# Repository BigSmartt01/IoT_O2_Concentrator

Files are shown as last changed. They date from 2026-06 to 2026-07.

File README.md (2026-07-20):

# IoT Oxygen Concentrator Integration

**Purity Monitoring, Alert System and Compressor Control**

A non-invasive integration module for PSA oxygen concentrators. The system monitors
oxygen purity on the outlet line, escalates alerts through five tiers as purity drops,
notifies a caregiver via SMS or voice call, and cuts compressor power only at true
system failure levels.

---
<p align="center">
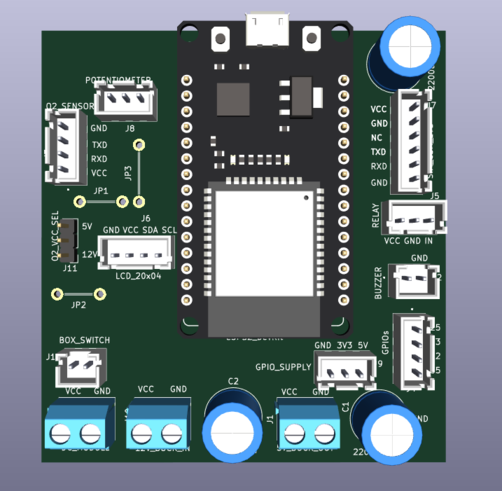
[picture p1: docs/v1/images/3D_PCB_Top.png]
  
</p>

## What This System Does

| Feature | Description |
|---|---|
| Purity monitoring | OCS-3FL2.0 ultrasonic sensor on post-filtration outlet (UART2) |
| Local display | LCD 2004 (I2C) shows O2%, flow, temperature, status, GSM signal, uptime |
| Five-tier alerts | NORMAL → WARNING → DANGER → SEVERE → CRITICAL, each with distinct buzzer pattern and response |
| Caregiver config | Number stored in NVS flash — configurable via USB serial, SMS command, **or the web portal** |
| Three input modes | Potentiometer (demo), WiFi captive portal (demo sliders), or real Sensor (UART) |
| Boot illusion | On boot, simulates a sensor warm-up ramp until a real sensor is connected — no hardware required to demo |
| Fail-safe relay | Compressor only cuts at CRITICAL (near-ambient O2, sustained) — every other tier keeps it running while alerting |

The concentrator itself is **not modified**. All integration is external in a separate enclosure.

---

## Hardware

| Component | Role |
|---|---|
| ESP32 DevKit (standard) | Main microcontroller, 3 UARTs, WiFi AP for captive portal |
| OCS-3FL2.0 sensor | Oxygen purity, flow, temperature (UART2, 12-byte packet) |
| SIM800L GSM EVB | SMS and voice call via Nigerian GSM network (UART1) |
| LCD 2004 + I2C backpack | Local display, 4 rows |
| 5V relay module + NPN driver (BC337) | Compressor power control, active-HIGH from GPIO |
| Active buzzer (5V) | Audible alert, pattern varies by tier |
| LM2596 buck converter | 12V to 5V regulated rail |
| 12V AC-DC module | Mains AC to 12V DC from concentrator supply |
| 2200uF electrolytic caps (x3) | Bulk capacitance on 5V rail, 12V rail, and SIM800L supply |
| Potentiometer 10k | Demo sensor substitute (ADC, GPIO 34) |

Full wiring, schematic, and PCB layout are documented in `docs/`.

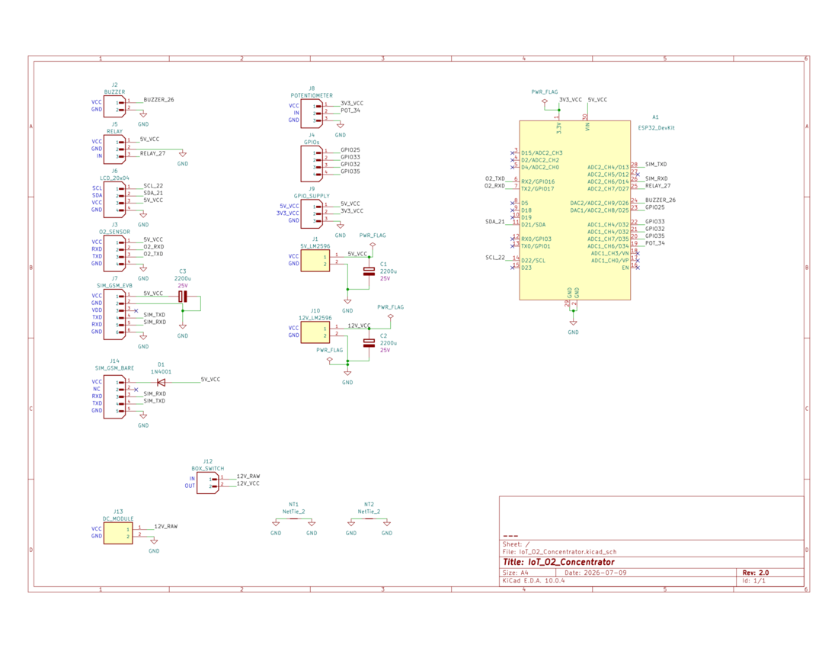
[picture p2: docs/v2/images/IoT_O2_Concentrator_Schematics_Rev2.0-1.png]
Schematic


---

## Project Structure

```
project-root/
├── firmware/               # Arduino sketch (.ino), config.h, portal_html.h
├── hardware/                # KiCad schematic, PCB layout, Gerber files
├── docs/                    # Full project documentation, diagrams, images
├── README.md                # This file
├── SETUP.md                 # Step-by-step setup guide for Arduino IDE
└── .gitignore
```

---

## Alert Tiers

The system escalates through five tiers based on O2 purity. Only the DANGER tier
and above place a voice call; only WARNING sends SMS. **The compressor keeps running
through every tier except CRITICAL** — the design assumes a caregiver may not respond
immediately, so oxygen delivery is only stopped once purity has effectively fallen to
ambient air levels, at which point the compressor was providing no therapeutic value anyway.

| Tier | O2 Purity | Buzzer | Caregiver Contact | Relay |
|---|---|---|---|---|
| NORMAL | ≥ 85% | Silent | — | ON |
| WARNING | 70% – 85% | Single beep, 1s cycle | SMS | ON |
| DANGER | 35% – 70% | Double beep, 1s cycle | Voice call | ON |
| SEVERE | 23% – 35% | Continuous tone | Voice call | ON |
| CRITICAL | < 23% (3 consecutive readings) | Continuous tone | Voice call | **OFF** |

Thresholds are runtime-adjustable (see [Configuration](#configuration-thresholds-and-caregiver-number) below)
and persist in NVS flash. Default fallback values live in `firmware/config.h`.

All alerts are suppressed for **30 seconds after boot** to allow the sensor warm-up
and GSM network registration to settle before any buzzer, SMS, or call can fire.

---

## Input Modes

The system supports three interchangeable data sources, switchable at any time from
the web portal without reflashing:

- **Potentiometer** — a physical demo knob on GPIO 34, mapped to 21%–95.6%
- **WiFi** — connect to the device's own captive portal and drag sliders for O2, flow, and temperature
- **Sensor** *(boots here by default)* — real UART2 data from the OCS-3FL2.0. If no real sensor is connected, the system runs a realistic warm-up illusion (ramping 21% → ~92% over ~15 seconds, then settling with slight jitter) so the full alert chain can be demonstrated with no hardware attached. The moment a real sensor sends valid packets, live data takes over automatically.

<p align="center">
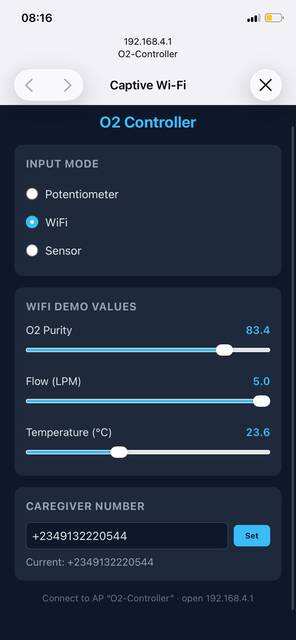
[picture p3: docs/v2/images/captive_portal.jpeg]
  <br>
  <em>WiFi captive portal for demo input and caregiver configuration</em>
</p>

---

## Firmware Architecture

The firmware uses **FreeRTOS** (built into the ESP32 Arduino core — no extra install needed).
Five tasks run concurrently, sharing data through two mutex-protected resources:

| Task | Core | Responsibility |
|---|---|---|
| `sensorTask` | 0 | Reads active input mode (pot / WiFi / sensor), updates shared O2 data |
| `displayTask` | 0 | Updates all 4 rows of the LCD every 500 ms |
| `webTask` | 0 | Hosts the WiFi AP, captive portal, and DNS redirect |
| `gsmTask` | 1 | Initialises modem on boot, monitors network registration every 5s |
| `configTask` | 1 | Handles USB serial and incoming SMS configuration commands |
| `alertTask` | 1 (highest priority) | Evaluates the 5-tier state machine, drives buzzer/relay/SMS/call |

`dataMutex` protects the shared sensor reading; `modemMutex` protects all TinyGSM AT command calls,
since multiple tasks share the same SIM800L UART.

---

## Quick Start

See [`SETUP.md`](SETUP.md) for the full step-by-step setup guide.

1. Install Arduino IDE 2.x
2. Add ESP32 board support
3. Install required libraries (listed in SETUP.md — includes ESPAsyncWebServer for the portal)
4. Open `firmware/IoT_O2_Concentrator.ino`
5. Set board to **ESP32 Dev Module**, select your COM port
6. Upload

---

## Configuration: Thresholds and Caregiver Number

Three interchangeable ways to configure the system — all write to the same NVS storage:

**1. Web portal (easiest, works in any input mode)**
Connect to WiFi network `O2-Controller` (password `12345678`), a captive portal should
open automatically. Enter the caregiver number in the "Caregiver Number" card and tap **Set**.

**2. USB Serial** (115200 baud)
```
SET NUM +2348012345678
SET WARN 72
SET NORM 87
STATUS
HELP
```

**3. SMS to the device SIM**
Send the same commands as SMS text to the SIM card installed in the SIM800L EVB.
The device replies with confirmation and deletes the processed message.

<p align="center">
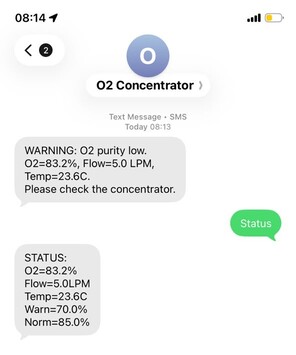
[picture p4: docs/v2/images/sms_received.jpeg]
  <br>
  <em>Caregiver receiving a live SMS alert</em>
</p>

All three methods are always available regardless of which input mode (pot/WiFi/sensor) is active.

---

## Documentation

Full design documentation is in the `docs/` folder. It covers:
- System architecture and power design
- Sensor UART protocol and 12-byte packet parsing
- Relay driver circuit (NPN, active-HIGH from GPIO)
- Five-tier alert logic and state machine
- KiCad schematic and PCB layout
- Wiring connection reference table
- Bill of Materials

---

*Project by Smart Ayodele.*
*README last updated to match firmware Rev 1.4*

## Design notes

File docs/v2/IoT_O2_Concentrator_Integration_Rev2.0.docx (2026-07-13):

IoT Oxygen Concentrator Integration

Purity Monitoring, Alert System and Compressor Control

Project Documentation | Rev 2.0 | Hardware v2.0 + Firmware Captive Portal

10 July 2026

Baseline | Hardware | Firmware | Docs layout
git tag v1.0 closed Phase 1–4 (EVB-era board + firmware) | KiCad schematic/PCB Rev 2.0 | Input modes + WiFi captive portal | docs/v1 archive · docs/v2 current

Rev 2.0 is the start of the Hardware v2 documentation line. All v1.x integration docs and legacy figures live under docs/v1/. Replace the figure placeholders in Sections 14–17 with updated Cirkit Designer, KiCad schematic, and PCB images when ready.

# Table of Contents

1. Project Overview

2. What Changed in Rev 2.0 (from git tag v1.0)

3. System Architecture

4. Power Architecture

5. Component Descriptions

6. OCS-3FL2.0 Oxygen Purity Sensor

7. UART Communication and Sensor Protocol

8. Relay Driver Circuit

9. SIM800 GSM — EVB and Bare Module

10. Alert Logic and Threshold Behaviour

11. LCD 2004 Display

12. Caregiver Number Configuration

13. ESP32 Pin Assignment

14. Enclosure and Mechanical Integration

15. Pictorial Wiring Diagram (placeholder)

16. Wiring Connection Reference Table

17. KiCad Schematic (placeholder)

18. PCB Layout (placeholder)

19. Firmware Architecture

20. Captive Portal and Input Modes

A. Sensor UART Packet Format

B. Bill of Materials Summary

C. config.h and portal_html.h Reference

D. Revision History

# 1. Project Overview

This document describes the design and implementation of an IoT integration system for an existing PSA (Pressure Swing Adsorption) oxygen concentrator. The concentrator is a commercial medical device. No modifications are made to its internal components. An external integration module is housed in a separate enclosure and connects via oxygen sampling tubing and wires for power and compressor control.

## 1.1 What the integration system does

Measures oxygen purity: One OCS-3FL2.0 ultrasonic sensor on the final oxygen outlet after all filtration stages. That reading is what the patient receives and drives all threshold decisions.

Provides visual feedback: LCD 2004 (20×4, I2C) shows live O2 %, flow, gas temperature, status, GSM signal quality, SIM state, and uptime.

Alerts the caregiver: Below the warning threshold the system beeps and can send SMS. Below the danger threshold the buzzer is continuous, a voice call is placed, and the compressor relay opens.

Controls the compressor: A 5 V relay module cuts compressor power in the danger state (fail-safe active-LOW module control as implemented in firmware).

Operates independently: No smartphone app is required for field use. Caregiver number and thresholds are stored in NVS and can be changed by USB serial or SMS. For laboratory demos, a WiFi captive portal (SSID O2-Controller) selects input source and can inject purity/flow/temp.

NOTE: This integration does not modify concentrator internal circuits. Connections are limited to (1) AC mains feed through the compressor relay and (2) the oxygen outlet tube for sensor sampling.

# 2. What Changed in Rev 2.0 (from git tag v1.0)

Git tag v1.0 closed the first hardware/firmware baseline: SIM800L evaluation board (EVB) on UART1, single-layer PCB with hand solder bridges JP1–JP3, O2 voltage selector jumper J11, and firmware without a captive portal. Hardware commit “Hardware v2.0” and the current firmware form the Rev 2.0 documentation baseline.

## 2.1 Hardware (KiCad schematic / PCB sheet rev 2.0)

Item | v1.0 (tag) | v2.0 (current)
GSM path | J7 SIM_GSM_EVB only (5 V EVB) | J7 EVB retained + J14 SIM_GSM_BARE for bare module
Bare module VCC | N/A | D1 1N4001 series drop from 5 V rail into bare module VCC
O2 sensor VCC select | J11 O2_VCC_SEL (5 V / 12 V jumper) | J11 removed — sensor accepts 5–12 V; no field jumper
Single-layer bridges | JP1, JP2, JP3 solder bridges (must close) | GND net ties for DRC-legal continuity
Libraries | Mixed paths | JST XH footprints/3D under hardware/libraries/
ESP32 pin map | Unchanged | Unchanged (see Section 13)

## 2.2 Firmware

Item | v1.0 baseline | v2.0 current
Input source | Potentiometer demo or manual UART swap | Runtime InputMode: POT / WIFI / SENSOR
Mode persistence | N/A | Always boots MODE_POT; never stored in NVS
WiFi | None | Soft-AP + DNS captive portal + AsyncWebServer
webTask | None | Core 0, prio 1, stack 8192; DNS every 10 ms
UI assets | N/A | portal_html.h (PORTAL_HTML in PROGMEM)
Tasks | 5 FreeRTOS tasks | 6 FreeRTOS tasks (+ webTask)
Sensor packet | 12-byte OCS-3FL2.0 (live path) | Same 12-byte parse in MODE_SENSOR
Build | Arduino IDE | Arduino IDE + PlatformIO platformio.ini

Populate either J7 (EVB) or J14 (bare SIM800 + D1), not both. Fit D1 only when using the bare path.

# 3. System Architecture

The integration module is built around a standard ESP32 DevKit. Sensors, GSM, display, buzzer, relay, demo pot, and WiFi AP all attach to it.

## 3.1 Power flow

AC Mains (concentrator) → 12 V AC-DC module → LM2596 buck → 5 V rail

12 V rail: OCS-3FL2.0 purity sensor VCC (Pin 1).

5 V rail: ESP32 DevKit VIN/5V, LCD 2004, active buzzer, 5 V relay module, SIM800L EVB VCC (J7), and — via D1 1N4001 — bare SIM800 VCC (J14). Bulk electrolytics C1/C2/C3 on 5 V, 12 V, and GSM rails.

3.3 V (ESP32 onboard LDO): I2C logic levels and UART logic toward ESP32 GPIO.

## 3.2 Data paths

Signal path | Interface | Direction | Notes
OCS-3FL2.0 ↔ ESP32 | UART2 @ 9600 8N1 | Sensor → MCU (auto report) | GPIO17 TX → sensor RXD; GPIO16 RX ← sensor TXD
SIM800 ↔ ESP32 | UART1 @ 9600 8N1 | Bidirectional AT | GPIO14 TX → modem RX; GPIO13 RX ← modem TX
LCD 2004 | I2C SDA/SCL | MCU → display | Addr 0x27 (or 0x3F); GPIO21/22
Relay module | GPIO26 | MCU → load | Active-LOW IN on typical modules
Buzzer | GPIO27 | MCU → output | Active 5 V buzzer
Potentiometer | GPIO34 ADC | Analog in | MODE_POT only
Captive portal | WiFi soft-AP | Phone ↔ ESP32 | SSID O2-Controller · 192.168.4.1

# 4. Power Architecture

## 4.1 12 V rail

Supplies the OCS-3FL2.0 on Pin 1 VCC. The sensor accepts DC 5–12 V; 12 V is taken from the AC-DC module without an extra conversion stage. There is no O2_VCC_SEL jumper in Hardware v2.0.

## 4.2 LM2596 5 V rail

Set the buck output to 5.0 V (no load) with a multimeter before installation. The rail powers ESP32, LCD, buzzer, relay, and GSM supply. Continuous capacity should be ≥ 2 A to cover SIM TX bursts.

## 4.3 GSM supply (EVB vs bare)

EVB (J7): Connect 5 V directly to EVB VCC. Leave VDD and RST floating. The EVB regulates the SIM800L chip internally.

Bare module (J14): Feed module VCC from 5 V through D1 (1N4001) so the module sees roughly 4.3–4.4 V under load, which is safer for bare SIM800 modules that expect ~3.4–4.4 V. Observe diode polarity.

Bulk capacitance: Place a large electrolytic (board uses 2200 µF 25 V class parts C1/C2/C3) close to the GSM supply pins. The radio can draw peaks near 2 A during transmit.

Rail | Voltage | Source | Consumers
12 V DC | 12 V | AC-DC module | OCS-3FL2.0 VCC
5 V DC | 5 V | LM2596 from 12 V | ESP32, LCD, buzzer, relay, GSM (EVB direct / bare via D1)
~4.3 V (bare only) | 5 V − Vf(D1) | D1 1N4001 | Bare SIM800 VCC on J14
3.3 V DC | 3.3 V | ESP32 LDO | GPIO/UART/I2C logic reference

# 5. Component Descriptions

## 5.1 ESP32 DevKit (standard)

Central MCU: UART0 USB debug, UART1 GSM, UART2 O2 sensor, I2C LCD, ADC pot, WiFi soft-AP. Dual-core FreeRTOS firmware (Arduino-ESP32).

## 5.2 LM2596 buck and 12 V AC-DC

LM2596 module steps 12 V to 5 V. AC-DC module converts concentrator mains to 12 V DC for the sensor and buck input.

## 5.3 LCD 2004 + I2C backpack

PCF8574 backpack, typically address 0x27. Four wires: VCC, GND, SDA, SCL.

## 5.4 Active buzzer and 5 V relay module

Active buzzer on GPIO27. Single-channel 5 V relay module on GPIO26 for compressor cut-out; module includes driver, opto, and flyback.

## 5.5 Bulk capacitors and D1

Three 2200 µF 25 V class electrolytics on the PCB (5 V, 12 V, GSM). D1 1N4001 is required only for the bare SIM800 path (J14).

## 5.6 Potentiometer (10 k)

Demo O2 source on GPIO34 when inputMode is MODE_POT. Remains available alongside WiFi and sensor modes; it is not removed from the board when the real sensor is used.

# 6. OCS-3FL2.0 Oxygen Purity Sensor

Industrial ultrasonic sensor for PSA concentrators: concentration, flow, and temperature over UART every 500 ms in automatic reporting mode.

Parameter | Value
Concentration range | 21.0 % to 95.6 % O2
Resolution / accuracy | 0.1 % / ±1.5 % FS (5–55 °C)
Flow range | 0 to 20 L/min (0.1 resolution)
UART | 9600 8N1, 3.3 V TTL, auto packet every 500 ms
Power | DC 5–12 V, ~50 mA (this design uses 12 V on Pin 1)
Warm-up | ~10 s to specified accuracy

## 6.1 Connector pinout (sensor J2 / board O2_SENSOR)

Pin | Function | Board / ESP32
1 | VCC | 12 V rail
2 | RXD (into sensor) | ESP32 GPIO17 UART2 TX
3 | TXD (from sensor) | ESP32 GPIO16 UART2 RX
4 | GND | System GND

Cross TX/RX intentionally: sensor TXD → ESP32 RX, sensor RXD → ESP32 TX. config.h: O2_TX_PIN=17, O2_RX_PIN=16.

## 6.2 Placement

Install on the final oxygen outlet after filtration. Observe the flow arrow on the sensor body.

## 6.3 Input modes vs “demo pot only”

v1 documentation described removing the pot when the sensor arrived. In Rev 2.0 firmware the pot stays installed. Operators select Potentiometer, WiFi, or Sensor from the captive portal. MODE_SENSOR enables the UART parser; MODE_POT continues to map ADC 0–4095 → 21.0–95.6 % O2.

# 7. UART Communication and Sensor Protocol

Both the OCS-3FL2.0 and SIM800 use 9600 8N1. This project uses automatic reporting mode for the sensor (no query required).

## 7.1 Packet structure (12 bytes — authoritative)

Earlier draft notes mentioned a 9-byte layout. The shipping firmware and Appendix A use the 12-byte OCS-3FL2.0 frame. Do not implement the 9-byte variant.

Byte | Field | Notes
0 | Header | 0x16
1 | Header | 0x09
2 | Header / mode | 0x01 (firmware accepts this header)
3–4 | O2 | (hi<<8|lo)/10.0 → %
5–6 | Flow | (hi<<8|lo)/10.0 → L/min
7–8 | Temp | (hi<<8|lo)/10.0 → °C
9–11 | Reserved + CS | Sum of all 12 bytes ≡ 0 (mod 256)

Sanity: discard packets with O2 < 15 % or O2 > 100 %. On checksum or range failure the firmware logs and does not update sharedData.

# 8. Relay Driver Circuit

A commercial 5 V single-channel relay module switches compressor AC. Interface: VCC, GND, IN (GPIO26). Typical modules are active-LOW (IN low energises coil). Firmware drives RELAY_PIN HIGH at boot (compressor off for low-level-trigger modules as coded) and uses HIGH for danger cut-out / LOW for compressor on in normal and warning states — match your module’s sense when wiring.

Module pin | Connect to | Notes
VCC | 5 V rail | Coil + logic supply
GND | System GND | Common ground
IN | ESP32 GPIO26 | Control
COM / NO | Compressor AC path | Mains-rated contacts only

DANGER: Mains wiring must follow local electrical safety rules. Isolate power before working on relay contacts.

# 9. SIM800 GSM — EVB and Bare Module

TinyGSM is configured for SIM800 (TINY_GSM_MODEM_SIM800). Hardware v2.0 supports two mutually exclusive physical interfaces.

## 9.1 Option A — SIM800L EVB (J7 SIM_GSM_EVB)

EVB pin | Connect to | Notes
VCC (5 V) | 5 V rail | Direct; no series diode
GND | System GND
SIM_RXD | ESP32 GPIO14 (UART1 TX) | MCU → modem
SIM_TXD | ESP32 GPIO13 (UART1 RX) | modem → MCU
VDD | NC | Leave floating — EVB logic reference out
RST | NC | Leave floating; reset via AT if needed

## 9.2 Option B — Bare SIM800 module (J14 SIM_GSM_BARE)

Bare path | Connect to | Notes
Module VCC | 5 V → D1 (1N4001) → module | Series drop; observe polarity
Module GND | System GND
Module RX | ESP32 GPIO14 TX | Same UART1 as EVB path
Module TX | ESP32 GPIO13 RX | Same UART1 as EVB path

Use J7 or J14, never both. Populate D1 for bare modules only.

## 9.3 Network

Quad-band GSM. Insert a provisioned Nigerian SIM. Firmware gsmTask restarts the modem, checks SIM, and attempts network registration every 5 s while holding modemMutex.

# 10. Alert Logic and Threshold Behaviour

Default thresholds (NVS-overridable): NORMAL when O2 > O2_NORMAL_MIN (85 %), WARNING when O2_WARNING_MIN ≤ O2 ≤ O2_NORMAL_MIN band behaviour as coded (warning below 85 % and above 70 %), DANGER when O2 < O2_WARNING_MIN (70 %).

State | O2 condition | Debounce | Actions
NORMAL | > 85 % (default) | counters clear | Compressor on, buzzer off, SMS/call flags reset
WARNING | between warn and normal | warningCount ≥ 3 | Compressor on, intermittent beep, one SMS
DANGER | < 70 % (default) | dangerCount ≥ 3 | Compressor off, solid beep, one voice call

alertTask (Core 1, priority 2, stack 8192) owns relay/buzzer and places SMS/call under modemMutex with exponential backoff retries (sendWithRetry).

# 11. LCD 2004 Display

Updated every DISPLAY_INTERVAL_MS (500 ms) by displayTask:

Row | Content
0 | O2 % and flow LPM
1 | Temperature °C and uptime seconds
2 | STATUS: NORMAL / WARNING / DANGER
3 | GSM RSSI, SIM OK/NO, gsmState name

# 12. Caregiver Number Configuration

Stored in NVS namespace "config" key caregiver_num. Also o2_warn_min and o2_norm_min. Loaded at boot. Identical command syntax on USB serial (115200) and inbound SMS.

Command | Example | Effect
SET WARN <value> | SET WARN 72 | Warning threshold → NVS
SET NORM <value> | SET NORM 87 | Normal threshold → NVS
SET NUM <e164> | SET NUM +2348012345678 | Caregiver MSISDN → NVS
STATUS | STATUS | O2 + thresholds
HELP | HELP | List commands

inputMode is not an NVS key. Power-cycle always returns to potentiometer mode.

# 13. ESP32 Pin Assignment

Authoritative map matches firmware/config.h (do not use older docs that listed UART1 on GPIO1/3).

GPIO | Function | Dir | Connects to
21 | I2C SDA | OD | LCD backpack SDA
22 | I2C SCL | OD | LCD backpack SCL
14 | UART1 TX (SIM_TX_PIN) | Out | Modem RX (EVB SIM_RXD or bare RX)
13 | UART1 RX (SIM_RX_PIN) | In | Modem TX (EVB SIM_TXD or bare TX)
17 | UART2 TX (O2_TX_PIN) | Out | Sensor Pin 2 RXD
16 | UART2 RX (O2_RX_PIN) | In | Sensor Pin 3 TXD
26 | RELAY_PIN | Out | Relay module IN
27 | BUZZER_PIN | Out | Buzzer +
34 | POT_PIN ADC | In | Pot wiper (MODE_POT)

Avoid GPIO 6–11 (flash). GPIO34 is input-only (ADC) — correct for pot wiper.

# 14. Enclosure and Mechanical Integration

Mount the custom PCB, ESP32, buck, AC-DC, GSM antenna clearance, LCD window, and cable glands in a medium insulating enclosure. Keep mains relay wiring segregated from low-voltage signal harnesses. Provide USB access for programming or a panel USB extension.

# 15. Pictorial Wiring Diagram

Phase-2 Cirkit Designer style diagram. Replace the placeholder with the Hardware v2.0 pictorial (include J14 bare path and remove J11 if shown).

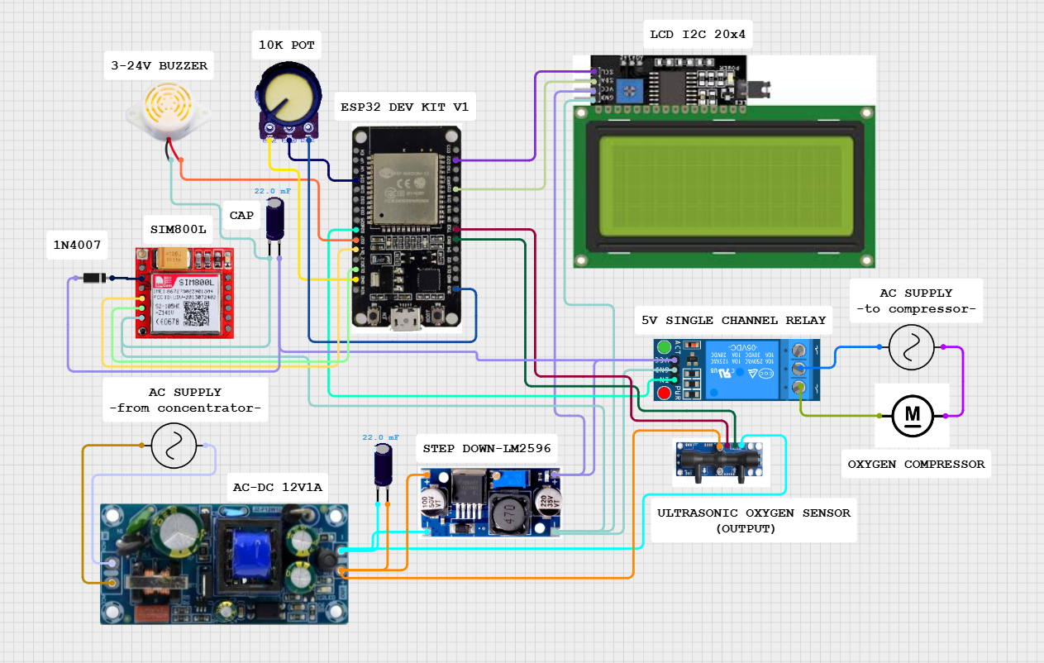
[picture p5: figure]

Figure 1: Pictorial wiring — v2.0 image.

# 16. Wiring Connection Reference Table

Wire-by-wire list aligned with config.h and Hardware v2.0 connectors.

From | From pin | To | To pin | Signal
AC source | L / N | AC-DC module | AC in | Mains
AC-DC | +12 V | LM2596 | VIN+ | 12 V
AC-DC | GND | LM2596 / GND bus | GND | GND
AC-DC | +12 V | O2 sensor | Pin 1 VCC | Sensor power
LM2596 | 5 V | ESP32 | VIN/5V | Logic power
LM2596 | 5 V | LCD / buzzer / relay VCC | VCC | 5 V loads
LM2596 | 5 V | J7 EVB VCC | VCC | GSM EVB (option A)
LM2596 | 5 V | D1 anode → cathode → J14 VCC | Bare VCC | GSM bare (option B)
Bulk C* | ± | Rails / GSM | local | 2200 µF class
ESP32 | GPIO26 | Relay | IN | Compressor control
ESP32 | GPIO27 | Buzzer | + | Alert
ESP32 | GPIO17 TX | Sensor | Pin 2 RXD | UART2
ESP32 | GPIO16 RX | Sensor | Pin 3 TXD | UART2
ESP32 | GPIO14 TX | Modem RX | SIM_RXD / bare RX | UART1
ESP32 | GPIO13 RX | Modem TX | SIM_TXD / bare TX | UART1
ESP32 | GPIO21/22 | LCD | SDA/SCL | I2C
ESP32 | GPIO34 | Pot | Wiper | ADC demo
ESP32 | 3V3 | Pot high | + | Divider
EVB only | VDD, RST | — | NC | Leave open
Relay | COM/NO | Compressor AC | switched live | Mains
All modules | GND | GND bus | — | Common reference

Common GND is mandatory. Floating grounds cause UART errors and modem brown-outs.

# 17. KiCad Schematic (Hardware v2.0)

Schematic sheet revision 2.0 in hardware/IoT_O2_Concentrator.kicad_sch. Connector summary:

Ref | Label | Type | Purpose
J1 | 5V_BUCK_OUT | Screw 2 | 5 V from LM2596
J2 | BUZZER | JST 2 | Active buzzer
J3 | O2_SENSOR | JST 4 | OCS-3FL2.0 VCC/RXD/TXD/GND
J4 | GPIOs | JST 4 | Spare GPIO breakout
J5 | RELAY | JST 3 | Relay VCC/GND/IN
J6 | LCD_20x04 | JST 4 | I2C LCD
J7 | SIM_GSM_EVB | JST 6 | SIM800L EVB (option A)
J8 | POTENTIOMETER | JST 3 | Demo pot
J9 | GPIO_SUPPLY | JST 4 | 5V/3V3/GND breakout
J10 | 12V_BUCK_IN | Screw 2 | 12 V into LM2596
J12 | BOX_SWITCH | JST 2 | Enclosure power switch
J13 | DC_MODULE | Screw 2 | Raw 12 V from AC-DC
J14 | SIM_GSM_BARE | JST | Bare SIM800 (option B)
D1 | 1N4001 | Diode | Series drop for J14 VCC
C1–C3 | 2200µ class | Electrolytic | Bulk on 5 V / 12 V / GSM
— | Net ties | GND | Replace former JP1–JP3 bridges

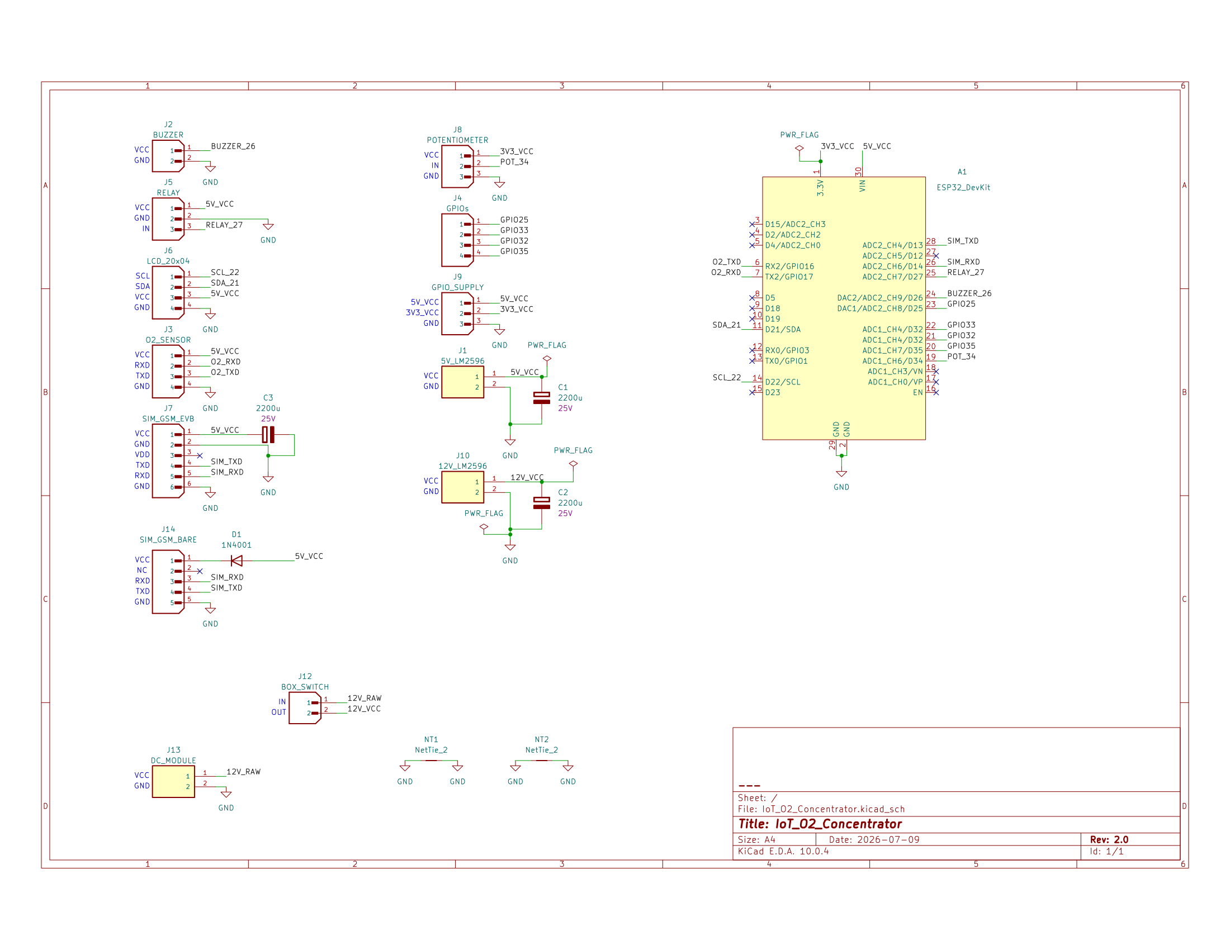
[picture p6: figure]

Figure 2: KiCad schematic — Hardware v2.0 export.

J11 O2_VCC_SEL does not exist on Hardware v2.0. Do not reintroduce it on new boards.

# 18. PCB Layout (Hardware v2.0)

Single-layer board with ground pour, JST and screw terminals for student plug-and-play. Routing cleanup after tag v1.0 replaced mandatory solder-bridge jumpers with GND net ties and added the bare GSM path.

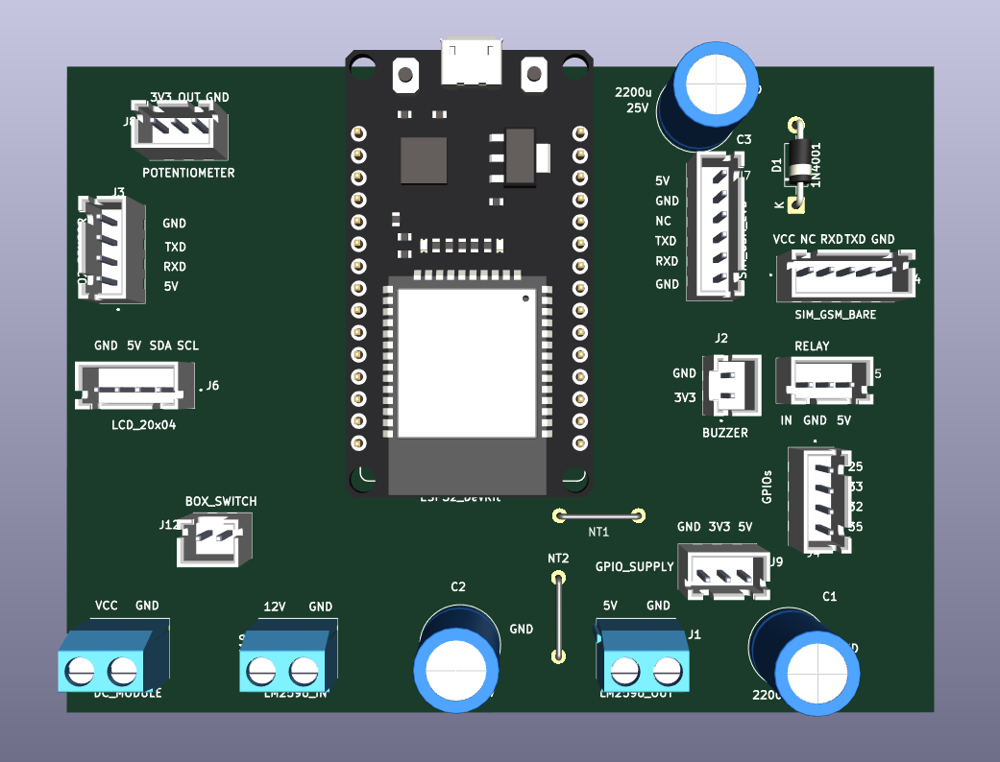
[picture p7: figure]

Figure 3: PCB layout / 3D — Hardware v2.0 renders.

Placement notes: centre ESP32 with USB accessible; keep bulk caps close to rails; group screw terminals for power; keep GSM antenna clear of large copper pours where possible.

# 19. Firmware Architecture

C++ / Arduino framework on ESP32 with FreeRTOS. Six concurrent tasks share SensorData and the modem under mutexes. Sources: firmware/IoT_O2_Concentrator/ (IoT_O2_Concentrator.ino, config.h, portal_html.h, platformio.ini).

## 19.1 Task summary

Task | Core | Prio | Stack | Loop | Role
sensorTask | 0 | 1 | 4096 | 50–500 ms | switch(inputMode): pot / wifi uptime / UART parse
displayTask | 0 | 1 | 4096 | 500 ms | LCD + RSSI/SIM snapshot
webTask | 0 | 1 | 8192 | 10 ms | AP + DNS + AsyncWebServer
gsmTask | 1 | 1 | 4096 | 5 s | Modem init + network registration
configTask | 1 | 1 | 4096 | 1 s | USB + SMS commands → NVS
alertTask | 1 | 2 | 8192 | 1 s | Thresholds, buzzer, relay, SMS/call

## 19.2 Mutexes

dataMutex protects SensorData (o2, flow, temp, uptime). modemMutex serialises all TinyGSM / AT access across displayTask, gsmTask, alertTask, and configTask. Never hold modemMutex across long blocking waits without need.

## 19.3 GSM state machine

volatile GsmState: IDLE, READY, NOSIM, CALLING, CALLED, SMS, SENT, RETRY, WAIT — shown on LCD row 3.

## 19.4 Alert debounce

dangerCount / warningCount require three consecutive qualifying samples before SMS or call. smsSent / callMade prevent repeat actions until O2 returns to NORMAL.

## 19.5 NVS keys

Key | Type | Default | Updated by
o2_warn_min | float | 70.0 | SET WARN
o2_norm_min | float | 85.0 | SET NORM
caregiver_num | string | +234… | SET NUM

# 20. Captive Portal and Input Modes

## 20.1 Soft-AP parameters (config.h)

Define | Value
WIFI_AP_SSID | O2-Controller
WIFI_AP_PASS | 12345678
WIFI_AP_IP | 192.168.4.1

## 20.2 webTask behaviour

Starts WIFI_AP, softAPConfig to 192.168.4.1/24, DNSServer on port 53 with wildcard redirect to the AP IP, AsyncWebServer on port 80. Loop: dnsServer.processNextRequest(); vTaskDelay(10 ms).

## 20.3 HTTP routes

Method / path | Behaviour
GET / | Mobile HTML UI from PORTAL_HTML (portal_html.h)
GET /setMode?mode=pot|wifi|sensor | Sets volatile inputMode; 200 OK
GET /update?purity&flow&temp | If MODE_WIFI, writes sharedData under dataMutex
GET /status | JSON {mode,o2,flow,temp} under dataMutex
GET /generate_204 | Redirect → http://192.168.4.1 (Android)
GET /hotspot-detect.html | Redirect (iOS)
GET /connecttest.txt | Redirect (Windows)
GET /redirect | Redirect

## 20.4 sensorTask modes

Mode | Behaviour | Period
MODE_POT (boot default) | ADC pot → O2 21.0–95.6 %; flow=0; temp=25; write sharedData | 500 ms
MODE_WIFI | Only sharedData.uptime refreshed; sliders via /update | 500 ms
MODE_SENSOR | Non-blocking UART2 drain; 12-byte parse + checksum + sanity | 50 ms

## 20.5 Portal UI behaviour

Title O2 Controller. Radio: Potentiometer (default), WiFi, Sensor. When WiFi is selected, show sliders: O2 21.0–95.6 step 0.1 default 85.0; Flow 0–20 step 0.1 default 5.0; Temp 5–55 step 0.1 default 25.0 with live value labels. Mode changes fetch /setMode; slider input fetches /update. On load, GET /status restores mode and values.

## 20.6 Libraries and build

LiquidCrystal_I2C, TinyGSM, ESPAsyncWebServer + AsyncTCP from ESP32Async GitHub only (https://github.com/ESP32Async/ESPAsyncWebServer and https://github.com/ESP32Async/AsyncTCP — do not use the old me-no-dev forks); ESP32 core WiFi, DNSServer, Preferences, FreeRTOS. PlatformIO env esp32dev verified ~14 % RAM / ~63 % Flash (Arduino-ESP32 2.x).

# Appendix A — Sensor UART Packet Format

12-byte automatic report. Validate header and checksum before use.

B0 | B1 | B2 | B3 | B4 | B5 | B6 | B7 | B8 | B9–11
0x16 | 0x09 | 0x01 | O2 hi | O2 lo | Fl hi | Fl lo | T hi | T lo | res/CS

O2 % = (b3<<8|b4)/10.0 Flow L/min = (b5<<8|b6)/10.0 Temp °C = (b7<<8|b8)/10.0

Checksum: sum(bytes[0..11]) mod 256 == 0.

# Appendix B — Bill of Materials Summary

S/N | Item | Qty | Notes
1 | OCS-3FL2.0 oxygen sensor | 1 | UART purity/flow/temp
2 | ESP32 DevKit (standard) | 1 | Main MCU + WiFi AP
3 | Custom PCB single-layer Rev 2.0 | 1 | With net ties, J7+J14
4 | LCD 2004 + I2C backpack | 1 | 0x27 / 0x3F
5 | 5 V relay module 1-ch | 1 | Compressor control
6 | 5 V active buzzer | 1 | Alerts
7 | SIM800L GSM EVB and/or bare SIM800 | 1 | Use one path
8 | 1N4001 diode | 1+ | Required for bare path D1
9 | 2200 µF 25 V electrolytic | 3 | C1/C2/C3 class bulk
10 | LM2596 buck module | 1 | 12→5 V
11 | 12 V AC-DC module | 1 | From concentrator AC
12 | SIM card (active) | 1 | Local carrier
13 | 10 k potentiometer | 1 | MODE_POT demo
14 | JST XH housings/cables | set | Match J2–J9, J12, J14
15 | Enclosure (medium) | 1 | Insulating
16 | BC337 / PC817 (optional spares) | 0–2 | Not required if using relay module

# Appendix C — config.h and portal_html.h Reference

Pin, timing, and WiFi defines (edit before flash; runtime thresholds use NVS).

#define I2C_SDA_PIN 21 / I2C_SCL_PIN 22 | SIM_TX_PIN 14 / SIM_RX_PIN 13 | O2_TX_PIN 17 / O2_RX_PIN 16 | RELAY_PIN 26 / BUZZER_PIN 27 / POT_PIN 34 | LCD_I2C_ADDR 0x27 | GSM_BAUD 9600 / O2_BAUD 9600

SENSOR_INTERVAL_MS 500 · DISPLAY_INTERVAL_MS 500 · ALERT_INTERVAL_MS 1000 · BUZZER_WARNING_MS 200 · BUZZER_WARNING_GAP 1000

O2_MIN_PERCENT 21.0 · O2_MAX_PERCENT 95.6 · ADC_MAX_VALUE 4095.0

WIFI_AP_SSID "O2-Controller" · WIFI_AP_PASS "12345678" · WIFI_AP_IP "192.168.4.1"

portal_html.h: static const char PORTAL_HTML[] PROGMEM — full captive-portal page (modes + sliders + JS).

Globals: enum InputMode { MODE_POT, MODE_WIFI, MODE_SENSOR }; volatile InputMode inputMode = MODE_POT; AsyncWebServer server(80); DNSServer dnsServer;

# Appendix D — Revision History

Rev | Date | Scope | Changes
1.0 | Jun 2025 | Phase 1 | Architecture, power, sensor protocol, relay, alerts, pins
1.1 | Jun 2025 | Phase 2 | Cirkit pictorial; interim hardware variants
1.2 | Jun 2026 | Phase 2 upd | LCD 2004, 5 V relay, standard ESP32, SIM800L EVB, pot demo
1.3 | 26 Jun 2026 | Phase 3–4 | KiCad + PCB figures, firmware tasks/NVS/SMS, 12-byte packet, BOM
1.4 | 10 Jul 2026 | Draft only | Incomplete patch attempt (superseded — do not use)
2.0 | 10 Jul 2026 | HW v2 + FW | Full rewrite for Hardware v2.0 (J14 bare SIM + D1, no J11, net ties) and captive-portal firmware (6 tasks, input modes, portal_html.h). Pins/wiring/packet/BOM reconciled to source. Figure placeholders for author image drop-in. Docs split docs/v1 vs docs/v2.

Project by Smart Ayodele. Documentation Rev 2.0 — July 2026.

Page 1 | IoT O2 Concentrator Integration | Rev 2.0

IoT Oxygen Concentrator Integration | Rev 2.0 | Hardware v2.0 + Firmware

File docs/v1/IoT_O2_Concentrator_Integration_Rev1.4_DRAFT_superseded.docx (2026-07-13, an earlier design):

IoT Oxygen Concentrator Integration

Purity Monitoring, Alert System and Compressor Control

Project Documentation | Rev 1.4 | Phase 1–4 + HW v2.0 / FW portal

10 July 2026

Phase 1 - Architecture | Phase 2 - Pictorial | Phase 3 - Schematic | Phase 4 - PCB

Phases 1–4 complete. Rev 1.4 documents Hardware PCB/schematic v2.0 (post git tag v1.0) and firmware captive-portal / multi-input-mode integration.

# Table of Contents

1. Project Overview

2. System Architecture

3. Power Architecture

4. Component Descriptions

5. OCS-3FL2.0 Oxygen Purity Sensor

6. UART Communication and Sensor Protocol

7. Relay Driver Circuit

8. SIM800L GSM EVB Module

9. Alert Logic and Threshold Behavior

10. LCD 2004 Display

11. Caregiver Number Configuration

12. ESP32 Pin Assignment

13. Enclosure and Mechanical Integration

14. Pictorial Wiring Diagram (Phase 2)

15. Wiring Connection Reference Table

16. KiCad Schematic (Phase 3)

17. PCB Layout (Phase 3)

18. Firmware Architecture

Appendix A - Sensor UART Packet Format

Appendix B - Bill of Materials Summary

Appendix C - config.h Reference

Appendix D - Revision History

# 1. Project Overview

This document describes the design and implementation of an IoT integration system for an existing PSA (Pressure Swing Adsorption) oxygen concentrator. The concentrator itself is a commercially acquired, working medical device. No modifications are made to its internal components. Instead, an external integration module is built and housed in a separate enclosure, connected to the concentrator via tubes (for oxygen sampling) and wires (for power and compressor control).

What the integration system does:

Measures oxygen purity: One OCS-3FL2.0 ultrasonic sensor is placed on the final oxygen outlet after all filtration stages. This reading represents what the patient actually receives and is used for all threshold decisions.

Provides visual feedback: An LCD 2004 display (20x4 character, I2C interface) shows the live O2 reading, flow rate, gas temperature, system status, GSM signal strength, and system uptime.

Alerts the caregiver: If purity drops below 85%, the system sounds a buzzer and sends an SMS to a registered caregiver number. If purity falls below 70%, the buzzer becomes more persistent and the system places a voice call instead.

Controls the compressor: A 5V relay module cuts power to the concentrator compressor when oxygen purity reaches the danger threshold, protecting the patient from critically low-purity output.

Operates independently: There is no smartphone app. The system is self-contained. Caregiver contact details are configurable via USB serial at setup or via incoming SMS command in the field.

Demo and input modes: The system boots in potentiometer mode (GPIO 34 ADC maps to O2%). A captive-portal WiFi AP (SSID O2-Controller) lets the operator select Potentiometer, WiFi, or Sensor mode. In WiFi mode, mobile sliders set purity, flow, and temperature for demos without the OCS-3FL2.0. Sensor mode enables the real UART purity sensor. Mode is runtime-only (not stored in NVS) and always restarts as Potentiometer.

NOTE: This integration does not modify the internal circuits of the oxygen concentrator. All connections to the concentrator are limited to: (1) the AC mains feed to the compressor relay, and (2) the oxygen outlet tube for sensor sampling.

# 2. System Architecture

The integration system is built around the standard ESP32 DevKit microcontroller, which serves as the central processing unit. All sensors, communication modules, output devices, and control circuitry connect to it.

Power flow:

AC Mains (concentrator) → 12V AC-DC Module → LM2596 Buck Converter → 5V Rail

12V Rail feeds: OCS-3FL2.0 purity sensor (Pin 1 VCC)

5V Rail feeds: ESP32 Devkit, SIM800L GSM EVB, LCD 2004, Active Buzzer, 5V Relay Module

3.3V (from ESP32 onboard LDO): I2C bus logic, sensor UART logic

Data paths:

Signal Path | Interface | Direction | Notes
OCS-3FL2.0 Sensor to ESP32 | UART2 @ 9600 baud | Sensor to MCU | 3.3V TTL, direct
SIM800L EVB to ESP32 | UART1 @ 9600 baud | Bidirectional | AT commands, 3.3V logic
LCD 2004 to ESP32 | I2C (SDA/SCL) | MCU to display | Address 0x27 or 0x3F
Relay module | GPIO (direct) | MCU to load | 5V relay module, IN pin
Buzzer | GPIO | MCU to output | Active buzzer, 5V
Potentiometer (demo) | ADC pin | Analog input | Simulates O2 reading

# 3. Power Architecture

The integration system draws all its power from the oxygen concentrator's existing AC supply. A dedicated 12V AC-to-DC module converts mains AC to a stable 12V DC rail. This 12V rail feeds the purity sensor directly and also supplies an LM2596 buck converter, which steps down to a regulated 5V for the rest of the system.

3.1 The 12V Rail

Supplies only the OCS-3FL2.0 purity sensor. The sensor accepts 5V to 12V on its power pin; 12V is used here to draw directly from the AC-DC module without an extra conversion stage.

3.2 The LM2596 Buck Converter (5V Rail)

The LM2596 is a switching step-down (buck) regulator capable of supplying up to 3A continuous. Before installation, adjust the onboard potentiometer to exactly 5.0V with no load connected and confirm with a multimeter. The 5V rail powers the ESP32 DevKit, SIM800L GSM EVB, LCD 2004, active buzzer, and 5V relay module.

3.3 SIM800L GSM EVB Supply

Hardware Rev 2.0 supports two GSM paths. The SIM800L GSM EVB (J7) still accepts 5 V directly on its VCC pin; no series diode is required on that path and the EVB onboard regulator feeds the SIM800L chip. Optionally, a bare SIM800 module may be wired on J14 (SIM_GSM_BARE). That path includes a series 1N4001 from the 5 V rail to drop module VCC into a safer range for bare modules that expect about 4.0–4.4 V. Use either EVB or bare module—not both at once. UART logic remains 3.3 V compatible with the ESP32. A bulk electrolytic (C3, 2200 µF class) remains across the GSM supply to absorb approximately 2 A TX bursts.

A 2000 uF electrolytic capacitor is placed across the EVB VCC and GND pins. The SIM800L chip inside the EVB draws burst currents up to 2A during GSM transmission regardless of board version. This capacitor absorbs those transients and prevents voltage dips on the 5V rail from affecting the ESP32 or other loads. Mount it as close to the EVB power pins as possible.

NOTE: Leave VDD and RST pins of the SIM800L EVB unconnected (floating). VDD is an internal logic reference output on the EVB - applying external voltage to it may damage the onboard regulator. RST is managed via AT commands only.

Rail | Voltage | Source | Consumers
12V DC | 12V | AC-DC module | OCS-3FL2.0 purity sensor (Pin 1 VCC)
5V DC | 5V | LM2596 from 12V | ESP32 DevKit, SIM800L EVB, LCD 2004, Buzzer, 5V Relay
3.3V DC | 3.3V | ESP32 onboard LDO | Sensor UART logic, I2C bus

# 4. Component Descriptions

This section describes every component in the integration module, its role in the system, and relevant operating parameters. Cross-reference with the Bill of Materials (BOM) in Appendix B.

4.1 ESP32 DevKit (Standard)

The standard ESP32 DevKit is the central microcontroller of this system. With one purity sensor and one GSM module, only two hardware UART channels are needed beyond UART0 (USB debug). The standard ESP32 has three UARTs total, which fits comfortably: UART0 for USB debug, UART1 for the SIM800L GSM EVB, and UART2 for the OCS-3FL2.0 purity sensor.

The DevKit includes a USB-to-serial bridge for programming, a 3.3V LDO regulator, and all GPIO broken out to 0.1-inch pitch headers. It runs at 240 MHz dual-core, has 520 KB SRAM, and features 12-bit ADC channels on multiple GPIO pins for the potentiometer demo input.

4.2 LM2596 Buck Converter Module

A switching step-down regulator pre-built module including the LM2596 IC, inductor, output capacitor, and adjustment potentiometer. Before installation, set output to exactly 5.2V using a multimeter with no load. Maximum output: 3A continuous.

4.3 12V AC-to-DC Power Module

Converts mains AC from the oxygen concentrator to regulated 12V DC. Tapped from the concentrator internal AC wiring before the compressor switch, so the integration system receives power whenever the concentrator is plugged in, regardless of relay state.

4.4 LCD 2004 with I2C Backpack

A 20-column, 4-row character LCD with a PCF8574 I2C backpack already soldered on. Reduces wiring to four connections: VCC (5V), GND, SDA, SCL. I2C address is 0x27. Run an I2C scanner sketch to confirm before flashing the main firmware. Contrast is adjusted via a small potentiometer on the backpack PCB.

4.5 Active Buzzer (5V)

Contains an internal oscillator and produces a tone when DC voltage is applied. Driven from an ESP32 GPIO pin. Pattern varies by alert level: short intermittent beeps for warning (below 85%), rapid persistent pattern for danger (below 70%).

4.6 5V Relay Module (1 channel)

A ready-made relay module with 5V coil. Integrates optocoupler, transistor driver, flyback diode, and status LED on a single PCB. Exposes only three interface pins: VCC (5V), GND, and IN (signal from ESP32 GPIO). The module is active-LOW: pulling IN LOW energizes the relay.

4.7 2000 uF Electrolytic Capacitor

Placed across SIM800L EVB VCC and GND as close to the module as possible. Absorbs burst current spikes up to 2A during GSM transmission. Polarity must be observed: positive lead to VCC, negative to GND. Voltage rating; 25V preferred.

4.8 Potentiometer (10k, demo only)

Wired as a voltage divider across 3.3V and GND. Wiper connected to ESP32 ADC pin GPIO 34. Firmware reads 12-bit ADC (0 to 4095) and maps linearly to O2 percentage 21% to 95.6%, matching the real sensor range. Allows complete testing of all alert logic, LCD display, buzzer, and GSM before the real sensor arrives. Removed and replaced with UART sensor wiring once the OCS-3FL2.0 hardware is available.

# 5. OCS-3FL2.0 Oxygen Purity Sensor

The OCS-3FL2.0 (WinPower Ultrasonic Oxygen Sensor, 2026 model) is an industrial-grade sensor designed for PSA oxygen concentrators. It measures oxygen concentration, gas flow rate, and gas temperature simultaneously, transmitting all three over a single UART interface every 500 ms. One sensor is installed on the final oxygen outlet after all filtration stages.

5.1 Key Specifications

Parameter | Value
Concentration range | 21% to 95.6% O2
Concentration resolution | 0.1%
Concentration accuracy | +/- 1.5% FS at 5 to 55 degrees C
Flow range | 0 to 20 L/min
Flow resolution | 0.1 L/min
UART output interval | Every 500 ms (automatic reporting mode)
UART baud rate | 9600 bps, 8N1
UART logic level | 3.3V TTL - direct connection to ESP32, no level shifting needed
Warm-up time | 10 seconds to specified accuracy
Power supply | DC 5V to 12V, 50 mA (12V used in this project)
Working temperature | 5 to 55 degrees C
Gas sample requirement | No condensation, dust filtration less than 1 um

5.2 Connector Pinout (J2 Socket)

Pin | Function | Notes
Pin 1 | VCC (Power input) | Connect to 12V DC
Pin 2 | RXD | Data input to sensor - connect to ESP32 TX pin
Pin 3 | TXD | Data output from sensor - connect to ESP32 RX pin
Pin 4 | GND | Common ground

NOTE: Sensor TXD connects to ESP32 RX pin. Sensor RXD connects to ESP32 TX pin. This cross-connection is correct. Connecting TX-to-TX and RX-to-RX is a common mistake that results in no data received.

5.3 Placement

The sensor is installed on the final oxygen outlet tube, after all filtration and molecular sieve stages. Follow the direction arrow marked on the sensor body - incorrect gas flow direction will produce wrong readings.

5.4 Demo Mode - Potentiometer Substitute

While the sensor is in transit, a potentiometer on GPIO 34 (ADC) simulates the output. The firmware reads the ADC value and maps it to O2 percentage 21% to 95.6%. Rotating the potentiometer fully tests all three alert states, buzzer patterns, LCD updates, and GSM messaging. When the sensor arrives, remove the potentiometer and connect UART2 instead.

# 6. UART Communication and Sensor Protocol

UART (Universal Asynchronous Receiver/Transmitter) transmits data one bit at a time over TX and RX wires. Both devices must use the same baud rate. The OCS-3FL2.0 uses 9600 bps, 8 data bits, 1 stop bit, no parity. The SIM800L EVB uses the same baud rate.

6.1 Sensor Operating Modes

Automatic reporting mode: Sensor transmits a packet every 500 ms without any command. Activates automatically if no query command is received within 4 seconds. This project uses automatic mode - the ESP32 simply listens on UART2 and parses incoming packets.

Query/response mode: The MCU sends a 4-byte query and the sensor responds immediately. Not used in this project but supported by the sensor.

6.2 Data Packet Structure (9 bytes, hexadecimal)

Byte Index | Hex Value | Field | Description
Byte 0 | 0x16 | Header 1 | Fixed - must equal 0x16
Byte 1 | 0x09 | Header 2 | Fixed - must equal 0x09
Byte 2 | 0x01 | Header 3 | Fixed - must equal 0x01
Bytes 3-4 | -- | O2 Concentration | (Byte3 x 256 + Byte4) / 10 = % O2
Bytes 5-6 | -- | Flow Rate | (Byte5 x 256 + Byte6) / 10 = L/min
Bytes 7-8 | -- | Temperature | (Byte7 x 256 + Byte8) / 10 = deg C
Byte 8 (last) | -- | Checksum (CS) | Sum of bytes 0 to 7, modulo 256

6.3 Parsing Logic (Arduino/C style)

uint8_t buf[9]; // Read 9 bytes from UART2 into buf[] if (buf[0]==0x16 && buf[1]==0x09 && buf[2]==0x01) { uint8_t cs = 0; for (int i = 0; i < 8; i++) cs += buf[i]; if (cs == buf[8]) { float o2 = (buf[3]*256 + buf[4]) / 10.0; // Oxygen % float flow = (buf[5]*256 + buf[6]) / 10.0; // L/min float temp = (buf[7]*256 + buf[8]) / 10.0; // deg C } }

# 7. Relay Driver Circuit

A 5V single-channel relay module switches the compressor power supply on or off based on oxygen purity level. The module integrates the optocoupler, transistor driver, flyback diode, and status LED onto a single PCB. No discrete driver components are needed externally. The module exposes three interface pins: VCC, GND, and IN.

7.1 Relay Module Interface

Module Pin | Connect To | Notes
VCC | 5V rail | Relay coil powered from 5V. Module draws 70-90 mA when energized.
GND | System GND | Common ground with ESP32 DevKit and all other components.
IN | ESP32 DevKit GPIO 26 | Signal input. Most modules are active-LOW: pull IN LOW to energize relay. Confirm with your specific module.

7.2 Relay Output Contacts (NO Configuration)

The relay contact block has three terminals: COM (common), NO (normally open), and NC (normally closed). The compressor AC supply wire is wired through COM and NO. In this configuration, the relay must be energized (active) for the compressor to run.

This is a deliberate fail-safe design: if the ESP32 DevKit loses power or crashes, the relay de-energizes, the NO contact opens, and the compressor stops. The system defaults to OFF rather than ON when control is lost.

DANGER: Do NOT use the NC (normally closed) terminal. Wiring through NC inverts the fail-safe logic and causes the compressor to run when the relay is de-energised. Always confirm the compressor stops when the IN signal is removed.

7.3 What is Inside the Relay Module (for reference)

Although no discrete components are built externally, understanding the relay module internals helps with troubleshooting and interpreting the Phase 3 schematic:

Optocoupler (e.g. PC817): Provides electrical isolation between the ESP32 signal side and the relay coil drive side. The ESP32 GPIO controls the optocoupler LED; the output drives the transistor without any direct electrical path between them.

NPN Transistor (e.g. BC337 equivalent): Switches relay coil current to GND when activated by the optocoupler. Saturates fully to minimize power dissipation.

Flyback Diode (1N4001 equivalent): Placed across the relay coil to absorb inductive voltage spikes when the coil is de-energised. Without this, the spike would destroy the transistor.

Status LED: Illuminates when the relay is energized. Useful for visual confirmation without a multimeter.

DANGER: The relay contacts switch mains AC voltage to the compressor. Never touch relay output terminals or compressor wiring while the system is powered. Treat the relay output side as live mains voltage at all times.

# 8. SIM800L GSM EVB Module

The SIM800L GSM EVB (Evaluation Board) is a plug-and-play version of the SIM800L cellular module mounted on a development board. The EVB handles power regulation and logic-level management internally. It is used for SMS and voice call initiation via AT commands over UART.

8.1 EVB Pinout and Connections

EVB Pin | Connect To | Notes
5V (VCC) | 5V rail | Main power. EVB regulates internally to chip voltage.
GND | System GND | Common ground.
SIM_TXD | ESP32 UART1 RX (GPIO 13) | Data from SIM800L to ESP32. 3.3V logic.
SIM_RXD | ESP32 UART1 TX (GPIO 14) | Data from ESP32 to SIM800L. 3.3V logic.
VDD | Leave open (NC) | Internal logic reference output. Do not connect externally.
RST | Leave open (NC) | Reset via AT command only. Do not connect.

NOTE: VDD and RST must be left unconnected. VDD is an output on the EVB, not an input. Connecting any voltage to VDD risks damaging the onboard regulator. RST is not needed.

8.2 Network Compatibility

SIM800L supports GSM 850/900/1800/1900 MHz quad-band. Nigerian networks (MTN, Airtel, Glo, 9mobile) use 900 MHz and 1800 MHz - both covered. Any active SIM with airtime for SMS and voice calls will work. Insert the SIM card with chip facing down into the EVB SIM holder.

8.3 Key AT Commands

AT Command | Function
AT | Basic check. Module responds with OK.
AT+CSQ | Signal strength (RSSI). Returns 0 to 31. Displayed on LCD.
AT+CMGF=1 | Set SMS to text mode. Required before sending SMS.
AT+CMGS="+234XXXXXXXXXX" | Send SMS. Follow with message text then 0x1A (Ctrl+Z) to send.
ATD+234XXXXXXXXXX; | Place voice call. Semicolon specifies voice, not data.
ATH | Hang up / end active call.
AT+CREG? | Network registration check. +CREG: 0,1 means registered.
AT+CMGL="ALL" | List all SMS. Used to detect incoming SET: configuration command.

# 9. Alert Logic and Threshold Behaviour

The alert system monitors oxygen purity from the OCS-3FL2.0 sensor on the post-filtration output. This represents what the patient actually receives and is the sole basis for all threshold decisions and relay control. During demo mode, the potentiometer ADC reading substitutes for the sensor value.

9.1 Threshold Definitions

Level | Threshold | Condition | System Response
Normal | Above 85% | Purity within safe range | No alert. Compressor runs. LCD shows NORMAL.
Warning (Level 1) | 70% to 85% | Purity below safe minimum | Buzzer: intermittent short beeps. SMS sent to caregiver. Compressor continues.
Danger (Level 2) | Below 70% | Critically low, risk to patient | Buzzer: rapid persistent pattern. Voice call placed. Relay cuts compressor.

9.2 State Machine

The firmware implements a three-state machine: NORMAL, WARNING, DANGER. To prevent false triggers from a single corrupted packet, a debounce count is used - the system only transitions to a higher alert state after 3 consecutive readings below the threshold. It transitions back to a lower state when readings recover, but buzzer and compressor reset only after sustained recovery.

9.3 SMS Alert

On entering WARNING, one SMS is sent to the caregiver number. The SMS is not repeated until the system recovers to NORMAL and drops back to WARNING again, preventing repeated messages.

Example SMS: 'ALERT: Oxygen purity low. Sensor reading: 82%. Uptime: 04:32 min. Please check the concentrator.'

9.4 Voice Call

On entering DANGER, a voice call is placed to the caregiver. The call is held open for a configurable duration (e.g. 30 seconds) then terminated with ATH. A retry attempts the call again if the first attempt fails. The relay simultaneously opens to cut compressor power.

9.5 Relay and Compressor Control

In NORMAL and WARNING states, the relay is energised (closed) and the compressor runs. In DANGER, the relay de-energises (open) and the compressor stops. Relay is wired NO (normally open) as a fail-safe: if the ESP32 DevKit loses power or crashes, the compressor stops automatically.

DANGER: Relay must be wired to the NO (normally open) terminal, not NC. Incorrect wiring inverts the fail-safe and causes the compressor to run unmonitored if the ESP32 loses power.

# 10. LCD 2004 Display

The LCD 2004 is a 20-column, 4-row character LCD with a PCF8574 I2C backpack already attached. It provides local real-time status without any phone or external device. Wiring is four connections: VCC (5V), GND, SDA, SCL. Contrast is adjusted via the small potentiometer on the backpack PCB.

10.1 I2C Address

The PCF8574 address is either 0x27 or 0x3F depending on the A0/A1/A2 solder bridge configuration on the backpack. Run an I2C scanner sketch on the ESP32 before uploading main firmware. Using the wrong address results in a blank display with no error message.

10.2 Proposed Display Layout

LCD Row | Content
Row 1 (cols 1-20) | O2: XX.X% FL: XX.XL/m
Row 2 (cols 1-20) | TMP: XX.X C UPTIME:XXXs
Row 3 (cols 1-20) | STATUS: NORMAL / WARNING / DANGER
Row 4 (cols 1-20) | GSM: XX SIM: OK / FAIL

Row 1: O2 percentage and flow rate. Row 2: gas temperature and uptime in seconds (switches to minutes after 99s). Row 3: current alert state. Row 4: GSM signal strength (CSQ 0-31) and SIM registration status. All rows update every 500 ms in sync with sensor data.

# 11. Caregiver Number Configuration

The caregiver phone number is stored in ESP32 non-volatile storage (NVS flash), which retains data after power loss. Two methods are available to set or update it.

Method A - USB Serial (Initial Setup)

Connect ESP32 to a computer via USB. Open a serial monitor (Arduino IDE, PuTTY, or similar) at 115200 baud. The system prints a menu on startup. Enter the caregiver number in international format (e.g. +2348012345678) and press Enter. The number saves to NVS. Recommended for initial configuration before deployment.

Method B - SMS Command (Field Update)

Send an SMS from any phone to the SIM card installed in the EVB. The message must follow this exact format:

SET:+2348099887766

The ESP32 monitors incoming SMS messages. On detecting a message starting with SET:, it extracts the number, validates it, saves it to NVS, and sends a confirmation SMS back. The previous number is overwritten.

NOTE: SET: is case-sensitive. The number must include country code starting with +. Example: +2348012345678 for a Nigerian number.

# 12. ESP32 Pin Assignment

GPIO pin assignments for the standard ESP32 DevKit. Avoid GPIO 6-11 (connected to internal flash SPI). GPIO 34-39 are input-only. Assignments are subject to revision in Phase 3 schematic.

GPIO | Function | Direction | Connected To
GPIO 16 | UART2 TX | Output | Sensor Pin 2 (RXD) - OCS-3FL2.0
GPIO 17 | UART2 RX | Input | Sensor Pin 3 (TXD) - OCS-3FL2.0
GPIO 14 | UART1 TX | Output | SIM800L EVB SIM_RXD
GPIO 13 | UART1 RX | Input | SIM800L EVB SIM_TXD
GPIO 21 | I2C SDA | Bidirectional | LCD 2004 I2C backpack SDA
GPIO 22 | I2C SCL | Output | LCD 2004 I2C backpack SCL
GPIO 26 | Relay control | Output | 5V Relay module IN pin
GPIO 27 | Buzzer | Output | Active buzzer positive terminal
GPIO 34 | ADC (demo only) | Input (ADC) | Potentiometer wiper - simulates O2 reading

# 13. Enclosure and Mechanical Integration

All integration electronics are housed in a white project enclosure box placed beside the oxygen concentrator. The concentrator itself remains physically unmodified. The following connections pass between the enclosure and the concentrator:

Connection | Type | Description
AC power input | Electrical wire | Tapped from concentrator AC supply to 12V AC-DC module inside enclosure
Compressor relay output | Electrical wire | Relay NO contact in series with compressor AC supply line
Oxygen sample tube | Silicone or PTFE tube | In-line with oxygen path after all filtration stages to OCS-3FL2.0 sensor

Panel cutouts required on the enclosure: LCD display window, buzzer grille, SIM card access slot or door, USB programming port, cable glands for oxygen tube and power/relay wires. The GSM antenna wire should exit the enclosure and be positioned away from metal surfaces for best signal reception.

# 14. Pictorial Wiring Diagram (Phase 2)

The pictorial wiring diagram below was created in Cirkit Designer. It shows all major components of the integration module and their connections. This is a functional representation to guide physical wiring, not a precise engineering schematic. The formal schematic will be delivered in Phase 3 using KiCad.

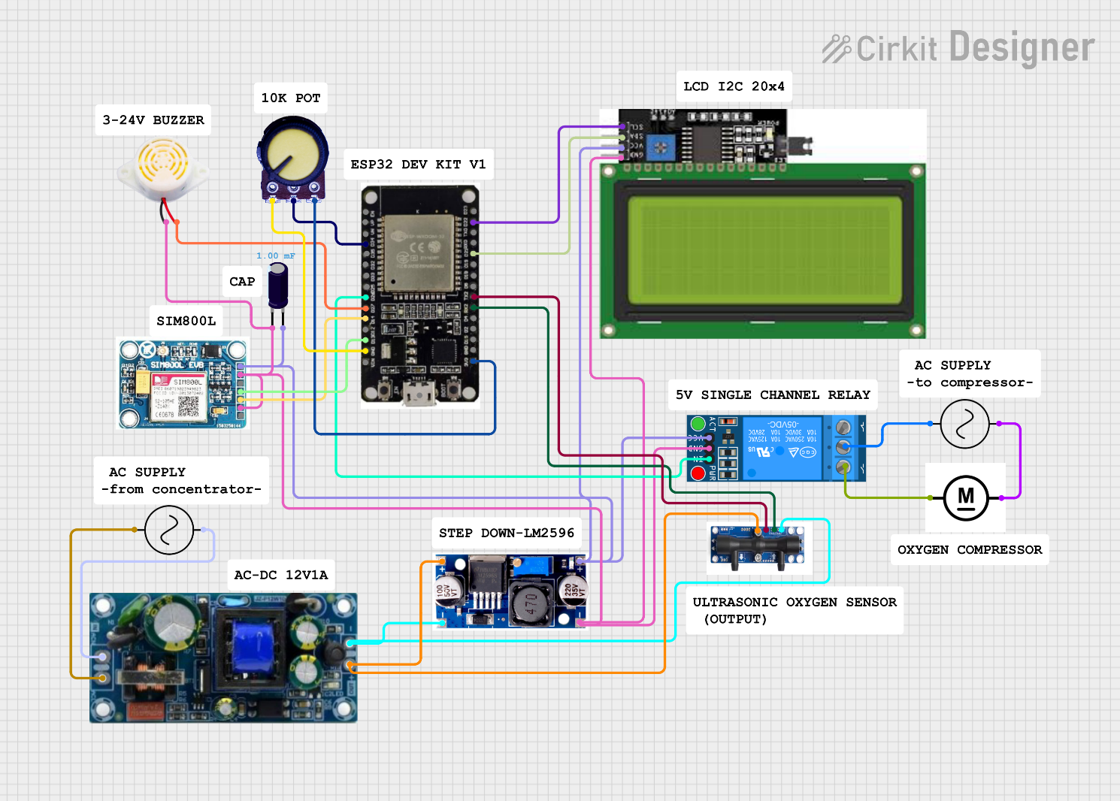
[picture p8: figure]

Figure 1: Pictorial wiring diagram - IoT O2 Concentrator Integration Module (Cirkit Designer, Phase 2). Components: AC-DC 12V module, LM2596 buck converter, ESP32 DevKit, SIM800L GSM EVB with 1000uF cap, 5V relay module, OCS-3FL2.0 oxygen sensor, LCD 2004 display, active buzzer, potentiometer (demo), compressor motor load.

14.1 Component Identification Guide

Component | Appearance in Diagram | Role
AC-DC 12V Module | Green PCB, bottom-left, connected to AC source symbol | Converts mains AC to 12V DC.
LM2596 Buck Converter | Blue module with inductor coil, bottom-centre | Steps 12V to regulated 5V.
ESP32 DevKit | Large board with antenna, centre | Main MCU. Processes sensor, controls relay, manages GSM.
SIM800L GSM EVB | Module with SIM slot, left of ESP32 | SMS and voice call to caregiver.
1000 uF Capacitor | Cylindrical component near EVB | Bulk cap on EVB 5V supply for GSM bursts.
5V Relay Module | Module with status LED, right of ESP32 | Switches compressor. Onboard driver, opto, flyback.
OCS-3FL2.0 Sensor | Small inline sensor module, right side | Post-filtration O2 purity. UART2.
LCD 2004 Display | Rectangular display with backpack, upper area | Shows readings, status, GSM, uptime.
Buzzer | Round component, top area | Audible alert for warning and danger states.
Potentiometer | Rotary component (demo only) | Simulates O2 via ADC. Removed when sensor arrives.
Compressor (Motor) | M symbol in circle, far right | Oxygen concentrator compressor load.
AC Source | Sine wave symbol, far right | Mains AC to compressor, switched by relay NO contacts.

# 15. Wiring Connection Reference Table

Complete wire-by-wire connection list. Use alongside the pictorial diagram during physical assembly.

From | From Pin | To | To Pin | Signal/Rail
AC Source | Live | AC-DC 12V Module | AC Input | Mains AC Live
AC Source | Neutral | AC-DC 12V Module | AC Input | Mains AC Neutral
AC-DC 12V Module | +12V Out | LM2596 Module | VIN+ | 12V DC Rail
AC-DC 12V Module | GND Out | LM2596 Module | VIN- | GND
AC-DC 12V Module | +12V Out | Sensor (J2) | Pin 1 VCC | 12V sensor power
AC-DC 12V Module | GND Out | System GND bus | -- | GND
LM2596 Module | VOUT+ (5V) | ESP32 DevKit | VIN/5V pin | 5V Rail
LM2596 Module | VOUT+ (5V) | SIM800L EVB | VCC (5V) | 5V to EVB
LM2596 Module | VOUT+ (5V) | 5V Relay Module | VCC | 5V relay coil
LM2596 Module | VOUT+ (5V) | LCD 2004 backpack | VCC | 5V display power
LM2596 Module | VOUT+ (5V) | 1000uF Cap (+) | -- | Bulk cap supply
LM2596 Module | VOUT- (GND) | System GND bus | -- | GND
1000uF Cap (+) | -- | SIM800L EVB | VCC (5V) | Parallel with EVB supply
1000uF Cap (-) | -- | System GND | -- | GND
ESP32 DevKit | GPIO 26 | 5V Relay Module | IN | Relay control signal
ESP32 DevKit | GPIO 27 | Buzzer (+) | -- | Buzzer drive
ESP32 DevKit | GPIO 16 (UART2 TX) | Sensor (J2) | Pin 2 RXD | Sensor command TX
ESP32 DevKit | GPIO 17 (UART2 RX) | Sensor (J2) | Pin 3 TXD | Sensor data RX
ESP32 DevKit | GPIO 1 (UART1 TX) | SIM800L EVB | SIM_RXD | AT command TX
ESP32 DevKit | GPIO 3 (UART1 RX) | SIM800L EVB | SIM_TXD | AT response RX
ESP32 DevKit | GPIO 21 (I2C SDA) | LCD backpack | SDA | I2C data
ESP32 DevKit | GPIO 22 (I2C SCL) | LCD backpack | SCL | I2C clock
ESP32 DevKit | GPIO 34 (ADC) | Potentiometer wiper | -- | Demo O2 (ADC input)
ESP32 DevKit | 3.3V | Potentiometer (+) | -- | Pot supply rail
ESP32 DevKit | GND | System GND bus | -- | GND
Potentiometer (-) | -- | System GND | -- | GND
SIM800L EVB | GND | System GND bus | -- | GND
SIM800L EVB | VDD | NOT CONNECTED | -- | Leave floating
SIM800L EVB | RST | NOT CONNECTED | -- | Leave floating
5V Relay Module | GND | System GND bus | -- | GND
5V Relay Module | COM | Compressor AC wire | -- | Mains switched line
5V Relay Module | NO | Compressor terminal | -- | Mains to compressor
Sensor (J2) | Pin 4 GND | System GND bus | -- | GND
Buzzer (-) | -- | System GND bus | -- | GND

NOTE: All GND connections must share a common reference point (GND bus). Floating or disconnected grounds between modules is the leading cause of erratic behaviour, UART failure, and SIM800L resets.

# Appendix A - Sensor UART Packet Quick Reference

The OCS-3FL2.0 transmits a 9-byte packet every 500 ms in automatic mode. Validate header (bytes 0-2) and checksum (byte 8) before using data.

Byte | 0 | 1 | 2 | 3 | 4 | 5 | 6 | 7-8 | Last
Field | Header | Header | Header | O2 Hi | O2 Lo | Fl Hi | Fl Lo | Temp | CS
Fixed | 0x16 | 0x09 | 0x01 | -- | -- | -- | -- | -- | SUM%256

O2 concentration (%) = (Byte3 x 256 + Byte4) / 10

Flow rate (L/min) = (Byte5 x 256 + Byte6) / 10

Temperature (deg C) = (Byte7 x 256 + Byte8) / 10

# Appendix B - Bill of Materials Summary

S/N | Item | Category | Unit | Qty | Source
1 | Oxygen Purity Sensor (OCS-3FL2.0) | Module | pcs | 1 | AliExpress
2 | ESP32 Dev Module (standard) | Module | pcs | 1 | Local - Mustech
3 | Breadboard | Component | pcs | 2 | Local - Mustech
4 | Veroboard - connecting | Component | pcs | 1 | Local - Mustech
5 | Veroboard - non-connecting | Component | pcs | 1 | Local - Mustech
6 | Flex Cables (2, 3, 4, 5 pin) | Component | set | 3 | Local - Mustech
7 | Flexible Soldering Cable | Component | pcs | 2 | Local - Mustech
8 | 5V Relay Module (1 channel) | Module | pcs | 1 | Local - Mustech
9 | 5V Active Buzzer | Component | pcs | 1 | Local - Mustech
10 | SIM800L GSM EVB Module | Module | pcs | 1 | Local - Mustech
11 | SIM Card (active, Nigeria) | Component | pcs | 1 | Local - SIM outlet
12 | 1N4001 Diode (spare) | Component | pcs | 4 | Local - Mustech
13 | 1000uF Electrolytic Cap (16V) | Component | pcs | 2 | Local - Mustech
14 | LM2596 Buck Converter Module | Module | pcs | 1 | Local - Mustech
15 | 12V AC-DC Module | Module | pcs | 1 | Local - Mustech
16 | White Enclosure Box (medium) | Component | pcs | 1 | Local - Mustech
17 | BC337 NPN Transistor (spare *) | Component | pcs | 2 | Local - Mustech
18 | PC817 Optocoupler (spare *) | Component | pcs | 2 | Local - Mustech
19 | LCD 2004 with I2C Backpack | Module | pcs | 1 | Local / AliExpress
20 | Potentiometer 10k (demo) | Component | pcs | 1 | Local - Mustech

NOTE: Items marked * (BC337, PC817) remain spares (relay module includes drivers). In HW v2.0, at least one 1N4001 is required on the bare SIM800 path (D1). EVB-only builds may leave D1 unpopulated. Prefer bulk caps 2200 µF 25 V class on 5 V, 12 V, and GSM rails as fitted on the PCB.

# 16. KiCad Schematic (Phase 3)

The schematic below was drawn in KiCad EDA 10.0.4 and represents the complete electrical design of the IoT O2 Concentrator integration board. It was reviewed and approved before PCB fabrication. All net names in the schematic correspond directly to the wiring reference table in Section 15.

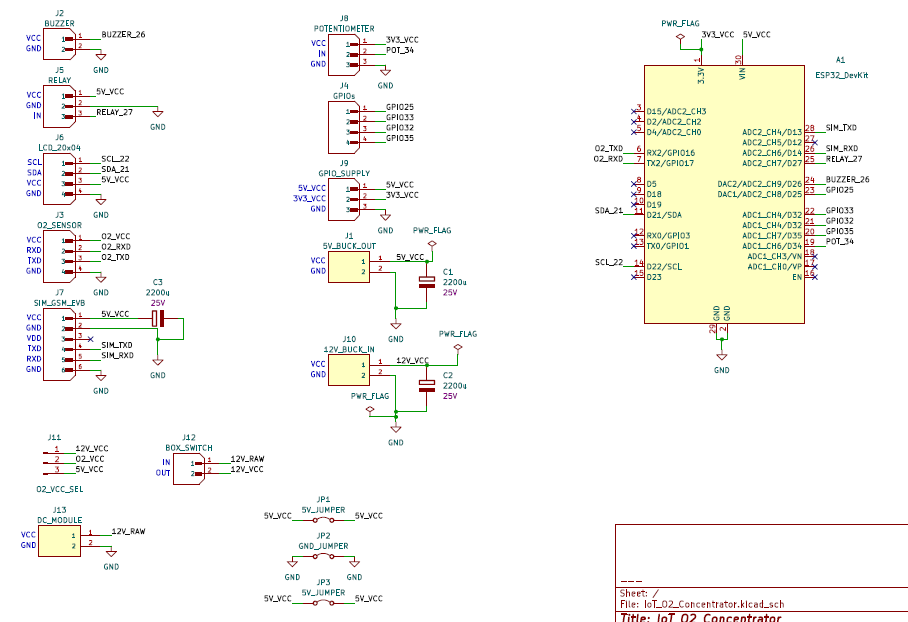
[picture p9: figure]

Figure 2: KiCad schematic - IoT O2 Concentrator Integration Board Rev 2.0 (schematic rev 2.0; post-v1.0 hardware). Base layout 2026-06; HW v2.0 2026-07.

16.1 Connector Summary

Ref | Label | Type | Pins | Purpose
J1 | 5V_BUCK_OUT | Screw terminal | 2 | 5V output from LM2596 buck converter
J2 | BUZZER | JST | 2 | Active buzzer
J3 | O2_SENSOR | JST | 4 | OCS-3FL2.0 (VCC, RXD, TXD, GND)
J4 | GPIOs | JST | 4 | Breakout: GPIO25, 33, 32, 35
J5 | RELAY | JST | 3 | 5V relay module (VCC, GND, IN)
J6 | LCD_20x04 | JST | 4 | LCD 2004 I2C (SCL, SDA, VCC, GND)
J7 | SIM_GSM_EVB | JST | 6 | SIM800L EVB (VCC, GND, VDD-NC, TXD, RXD, GND). HW v2.0 also adds J14 SIM_GSM_BARE for bare module + 1N4001 VCC drop — use J7 or J14, not both.
J8 | POTENTIOMETER | JST | 3 | Demo pot (VCC, wiper, GND)
J9 | GPIO_SUPPLY | JST | 4 | Supply breakout (5V, 3V3, GND, GND)
J10 | 12V_BUCK_IN | Screw terminal | 2 | 12V input to LM2596
J11 | REMOVED (v2.0) | Jumper 3-pin | 3 | Removed in HW v2.0 — sensor accepts 5–12 V
J12 | BOX_SWITCH | JST | 2 | Power switch between J13 raw and J10 system
J13 | DC_MODULE | Screw terminal | 2 | Raw 12V from AC-DC module
Net ties (GND) | Bridges | Solder bridge | 2 | GND net-tie continuity (replaces JP bridges)

# 17. PCB Layout (Phase 3)

The PCB is a single-layer (one-sided) board designed for local etching. Hardware Rev 2.0 cleans up routing after git tag v1.0: former solder-bridge jumpers (JP1–JP3) are replaced with schematic net ties (GND continuity for DRC), dual GSM connectors are provided (J7 EVB and J14 bare SIM800 with 1N4001 drop), and the O2 sensor voltage selector jumper (J11) is removed because the OCS-3FL2.0 accepts 5–12 V. A ground pour still covers unused copper. Connectors remain JST or screw terminal for plug-and-play student builds.

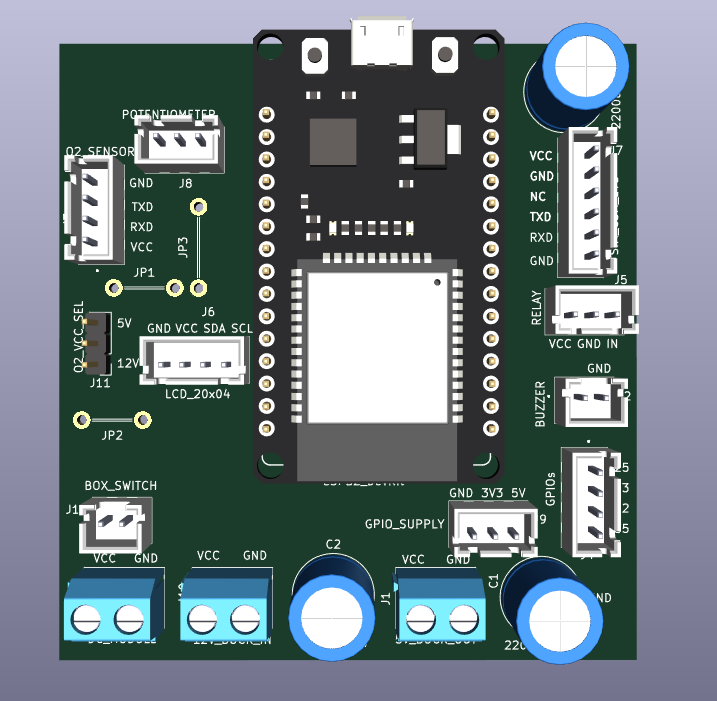
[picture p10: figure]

Figure 3: PCB 3D render (top view) - IoT O2 Concentrator Integration Board Rev 2.0. Single copper layer with ground pour and GND net ties.

17.1 Component Placement Notes

ESP32 DevKit - centred on the board. USB port faces the top edge for easy programming access without opening the enclosure (route a USB extension to the enclosure panel if needed).

Large capacitors (C1, C2, C3, 2200uF 25V) - placed at the board corners and top-right. Keep leads short and solder both legs fully.

Screw terminals (J1, J10, J13) - bottom edge of the board. High-current connections kept together and away from signal connectors.

JST connectors - distributed around the board perimeter matching their connected component position in the enclosure.

O2 sensor supply (Rev 2.0) - J11 REMOVED (v2.0) removed. Sensor VCC is fixed from the design rail (5–12 V accepted by OCS-3FL2.0); no field jumper selection required.

GND net ties (Rev 2.0) - replace the earlier JP1–JP3 solder bridges. Net ties provide DRC-legal copper continuity on the single-layer board without mandatory hand-soldered jumpers on those nets.

NOTE (Rev 2.0): Confirm GND net ties are present on the fabricated board (they are copper features, not optional links). For bare SIM800 on J14, fit D1 (1N4001) in the correct polarity. Do not populate both GSM paths simultaneously.

# 18. Firmware Architecture

with six concurrent FreeRTOS tasks sharing data through mutex-protected structures (sensor, display, web/captive portal, GSM, config, alert).

18.1 Task Summary

Task | Core | Priority | Stack | Interval | Responsibility
sensorTask | 0 | 1 | 4096B | 500ms | Mode-switched input: MODE_POT (ADC pot), MODE_WIFI (uptime only; values from portal), MODE_SENSOR (OCS-3FL2.0 UART2). Updates shared SensorData under dataMutex.
displayTask | 0 | 1 | 4096B | 500ms | Reads shared SensorData. Updates all 4 rows of LCD 2004. Reads GSM RSSI and SIM status.
gsmTask | 1 | 1 | 4096B | 5000ms | Initialises modem on boot. Monitors network registration every 5 seconds. Updates gsmState enum.
configTask | 1 | 1 | 4096B | 1000ms | Handles USB serial commands and incoming SMS commands. Updates thresholds and caregiver number in NVS.
alertTask | 1 | 2 | 8192B | 1000ms | Highest priority on Core 1. Monitors O2 level, manages buzzer patterns, relay state, SMS and voice call.

18.2 Shared Data and Mutex Protection

Two mutexes protect shared resources. dataMutex protects the SensorData struct shared between sensorTask (writer) and displayTask/alertTask (readers). modemMutex protects all TinyGSM modem calls since multiple tasks (displayTask, gsmTask, alertTask, configTask) use the same UART1 simSerial interface. Any task that calls the modem must take modemMutex first and release it immediately after, never holding it across a vTaskDelay.

18.3 GSM State Machine

A volatile enum GsmState drives the LCD Row 4 display and guards alert actions. States: IDLE (startup), READY (registered on network), NOSIM (no SIM detected), CALLING (placing call), CALLED (call placed successfully), SMS (sending message), SENT (message sent), RETRY (last action failed), WAIT (network unavailable during alert).

18.4 Alert State Machine

alertTask uses debounce counters (dangerCount, warningCount) to prevent false triggers from a single corrupted packet. The system only transitions to WARNING or DANGER after 3 consecutive readings below the threshold. SMS and call flags (smsSent, callMade) prevent repeated alerts per event. Flags reset when O2 recovers to NORMAL.

State | O2 Reading | dangerCount | warningCount | Actions
NORMAL | > 85% | 0 | 0 | Relay LOW (compressor ON), buzzer OFF, flags reset
WARNING | 70% to 85% | 0 | >= 3 | Relay LOW (compressor ON), intermittent buzzer, one SMS sent
DANGER | < 70% | >= 3 | 0 | Relay HIGH (compressor OFF), continuous buzzer, one voice call placed

18.5 NVS Configuration (Persistent Storage)

Three values are stored in ESP32 NVS flash under the namespace 'config' and survive power cycles. They are loaded at boot and can be updated via USB serial or SMS command.

NVS Key | Type | Default | Updated by
o2_warn_min | float | 70.0 | SET WARN <value> via serial or SMS
o2_norm_min | float | 85.0 | SET NORM <value> via serial or SMS
caregiver_num | String | +2349036644559 | SET NUM <number> via serial or SMS

18.6 Configuration Commands

Commands work identically over USB serial monitor (115200 baud) and SMS to the device SIM:

Command | Example | Effect
SET WARN <value> | SET WARN 72 | Sets warning threshold to 72%. Saved to NVS.
SET NORM <value> | SET NORM 87 | Sets normal threshold to 87%. Saved to NVS.
SET NUM <number> | SET NUM +2348012345678 | Updates caregiver number. Saved to NVS.
STATUS | STATUS | Returns current O2 reading and both thresholds.
HELP | HELP | Lists all available commands.

18.7 Input Modes (Potentiometer / WiFi / Sensor)

sensorTask switches on a volatile InputMode (MODE_POT, MODE_WIFI, MODE_SENSOR). The device always boots in MODE_POT and never stores the mode in NVS. MODE_POT maps GPIO 34 ADC (0–4095) to 21.0–95.6% O2 with flow=0 and temp=25 °C. MODE_WIFI only refreshes sharedData.uptime; purity/flow/temp are written by the HTTP /update handler from the captive-portal sliders. MODE_SENSOR non-blocking-drains UART2 and parses 12-byte OCS-3FL2.0 frames (header 0x16 0x09 0x01, checksum sum of 12 bytes ≡ 0 mod 256, O2 sanity 15–100%). Mode is selected from the portal radio buttons via GET /setMode.

NOTE: The real sensor task uses UART2 (GPIO 16 TX, GPIO 17 RX) at 9600 baud. Ensure the sensor J2 connector is wired correctly: sensor Pin 2 (RXD) to ESP32 GPIO 16, sensor Pin 3 (TXD) to ESP32 GPIO 17. TX crosses to RX - this is correct and intentional.

18.8 Captive Portal and webTask

webTask (Core 0, priority 1, stack 8192) starts a WiFi soft-AP (SSID O2-Controller, password 1234567890, IP 192.168.4.1), a DNSServer on port 53 that redirects all hostnames to the AP IP, and an AsyncWebServer on port 80. The task loop only runs dnsServer.processNextRequest() with a 10 ms delay so captive-portal detection stays responsive. HTTP handlers run in the async stack.

Portal routes: GET / serves the mobile HTML UI from portal_html.h (PROGMEM). GET /setMode?mode=pot|wifi|sensor updates inputMode. GET /update?purity=&flow=&temp= writes sharedData only when MODE_WIFI (under dataMutex). GET /status returns JSON {mode,o2,flow,temp}. Captive triggers /generate_204, /hotspot-detect.html, /connecttest.txt, and /redirect send users to http://192.168.4.1.

18.9 Build notes (Rev 1.4)

Libraries: LiquidCrystal_I2C, TinyGSM, ESPAsyncWebServer, AsyncTCP (plus ESP32 core WiFi/DNSServer/FreeRTOS). A PlatformIO project file (platformio.ini) is provided under firmware/IoT_O2_Concentrator for headless builds; Arduino IDE remains supported. Verified build: ESP32 Dev Module — approx. 14% RAM / 63% Flash (Arduino-ESP32 2.x / PlatformIO espressif32).

19. Hardware Rev 2.0 Summary (post git tag v1.0)

Git tag v1.0 marked the Phase-3/4 firmware + documentation baseline with SIM800L EVB-oriented hardware. Subsequent Hardware v2.0 work (schematic sheet rev 2.0) adds bare-module GSM support and PCB routing cleanup without changing ESP32 pin assignments used by firmware: SIM UART1 GPIO14 TX / GPIO13 RX; O2 UART2 GPIO17 TX / GPIO16 RX; relay GPIO26; buzzer GPIO27; pot GPIO34; I2C SDA/SCL 21/22.

Key PCB/schematic deltas vs tag v1.0: (1) J14 SIM_GSM_BARE + D1 1N4001 VCC drop for bare SIM800; (2) J7 SIM_GSM_EVB retained for 5 V EVB modules; (3) J11 O2_VCC_SEL removed; (4) JP1–JP3 hand bridges replaced by GND net ties; (5) footprint/library path cleanup for JST XH connectors. Re-export Gerbers from the Rev 2.0 KiCad project before fabrication.

# Appendix A - Sensor UART Packet Quick Reference

The OCS-3FL2.0 transmits a 12-byte packet every 500 ms in automatic mode. Validate header (bytes 0-2) and checksum (all 12 bytes sum to 0 mod 256) before using data.

Byte | 0 | 1 | 2 | 3 | 4 | 5 | 6 | 7 | 8 | 9-11
Field | Hdr | Hdr | Hdr | O2 Hi | O2 Lo | Fl Hi | Fl Lo | Tmp Hi | Tmp Lo | Reserved/CS
Value | 0x16 | 0x09 | 0x01 | -- | -- | -- | -- | -- | -- | sum all 12 = 0

O2 concentration (%) = (buf[3] << 8 | buf[4]) / 10.0

Flow rate (L/min) = (buf[5] << 8 | buf[6]) / 10.0

Temperature (deg C) = (buf[7] << 8 | buf[8]) / 10.0

Checksum validation: sum all 12 bytes, result must equal 0 (mod 256).

# Appendix B - Bill of Materials Summary

S/N | Item | Category | Unit | Qty | Source
1 | Oxygen Purity Sensor (OCS-3FL2.0) | Module | pcs | 1 | AliExpress
2 | ESP32 Dev Module (standard) | Module | pcs | 1 | Local - Mustech
3 | Breadboard | Component | pcs | 2 | Local - Mustech
4 | Veroboard - connecting | Component | pcs | 1 | Local - Mustech
5 | Veroboard - non-connecting | Component | pcs | 1 | Local - Mustech
6 | Flex Cables (2, 3, 4, 5 pin) | Component | set | 3 | Local - Mustech
7 | Flexible Soldering Cable | Component | pcs | 2 | Local - Mustech
8 | 5V Relay Module (1 channel) | Module | pcs | 1 | Local - Mustech
9 | 5V Active Buzzer | Component | pcs | 1 | Local - Mustech
10 | SIM800L GSM EVB Module | Module | pcs | 1 | Local - Mustech
11 | SIM Card (active, Nigeria) | Component | pcs | 1 | Local - SIM outlet
12 | 1N4001 Diode (spare) | Component | pcs | 4 | Local - Mustech
13 | 2200uF Electrolytic Cap (25V) | Component | pcs | 3 | Local - Mustech
14 | LM2596 Buck Converter Module | Module | pcs | 1 | Local - Mustech
15 | 12V AC-DC Module | Module | pcs | 1 | Local - Mustech
16 | White Enclosure Box (medium) | Component | pcs | 1 | Local - Mustech
17 | BC337 NPN Transistor (spare *) | Component | pcs | 2 | Local - Mustech
18 | PC817 Optocoupler (spare *) | Component | pcs | 2 | Local - Mustech
19 | LCD 2004 with I2C Backpack | Module | pcs | 1 | Local / AliExpress
20 | Potentiometer 10k (demo) | Component | pcs | 1 | Local - Mustech
21 | Custom PCB (single layer) | PCB | pcs | 1 | Local fabrication

In HW v2.0, populate D1 (1N4001) when using bare SIM800 on J14. Capacitor quantity remains 3× bulk electrolytics (C1 5 V rail, C2 12 V rail, C3 GSM supply), 2200 µF 25 V class. PCB is custom single-layer Rev 2.0.

# Appendix C - config.h Reference

All configurable constants are centralised in config.h. Edit this file before compiling to adjust pin assignments, timing, or default thresholds. Runtime changes use NVS (see Section 18.5).

#ifndef CONFIG_H #define CONFIG_H // === Pin Assignments === #define RELAY_PIN 26 // 5V relay module IN #define BUZZER_PIN 27 // Active buzzer #define POT_PIN 34 // ADC - demo potentiometer #define LCD_I2C_ADDR 0x27 // Change to 0x3F if blank display #define SIM_TX_PIN 14 // UART1 TX to SIM800L EVB SIM_RXD #define SIM_RX_PIN 13 // UART1 RX from SIM800L EVB SIM_TXD #define O2_TX_PIN 16 // UART2 TX to sensor Pin 2 RXD #define O2_RX_PIN 17 // UART2 RX from sensor Pin 3 TXD // === Baud Rates === #define GSM_BAUD 9600 #define O2_BAUD 9600 // === Timing (ms) === #define SENSOR_INTERVAL_MS 500 #define DISPLAY_INTERVAL_MS 500 #define ALERT_INTERVAL_MS 1000 #define BUZZER_WARNING_MS 200 // Beep duration #define BUZZER_WARNING_GAP 1000 // Gap between beeps // === Demo Mode ADC Mapping === #define O2_MIN_PERCENT 21.0 #define O2_MAX_PERCENT 95.6 #define ADC_MAX_VALUE 4095.0 #endif

# Appendix D - Revision History

Revision | Date | Phase | Changes
Rev 1.0 | June 2025 | Phase 1 | Initial release. System architecture, power design, sensor protocol, relay driver, alert logic, pin assignment, enclosure overview.
Rev 1.1 | June 2025 | Phase 2 | Pictorial diagram added (Cirkit Designer). Relay updated to 12V module. OLED corrected to 1.5-inch 128x128. Wiring table and BOM appendix added.
Rev 1.2 | June 2026 | Phase 2 Update | Hardware changes: LCD 2004 replaces OLED. 5V relay replaces 12V relay. Single sensor (post-filter only). Standard ESP32 replaces S3. SIM800L GSM EVB - 5V direct, VDD/RST open. Potentiometer ADC demo added.
Rev 1.3 | 26 Jun 2026 | Phase 3 + 4 | KiCad schematic and PCB 3D render added (Sections 16, 17). Firmware architecture section added (Section 18) covering FreeRTOS tasks, mutexes, GSM and alert state machines, NVS config, SMS/serial commands, and sensor swap guide. Appendix C (config.h reference) added. Capacitor qty corrected to 3x 2200uF 25V. PCB added to BOM. Packet length corrected to 12 bytes. Document is complete for fabrication and deployment.
Rev 1.4 | 10 Jul 2026 | HW v2.0 + FW | Hardware schematic/PCB advanced to Rev 2.0 after git tag v1.0: bare SIM800 module connector (J14) with 1N4001 series drop from 5 V; dual-path with SIM800L EVB (J7); removed O2 sensor voltage selector J11; JP1–JP3 solder bridges replaced with GND net ties. Firmware: captive-portal WiFi AP (O2-Controller), DNS redirect, ESPAsyncWebServer webTask; input modes pot/WiFi/sensor; portal_html.h; WiFi defines in config.h. PlatformIO build verified.

Page 1 | IoT O2 Concentrator Integration | CONFIDENTIAL

IoT Oxygen Concentrator Integration Project Documentation | Rev 1.4

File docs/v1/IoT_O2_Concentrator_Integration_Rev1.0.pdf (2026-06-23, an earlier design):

IoT Oxygen Concentrator Integration - Project Documentation | CONFIDENTIAL

# IoT Oxygen Concentrator Integration

Purity Monitoring, Alert System and Compressor Control

Phase 1 of 4 | System Architecture and Design Reference | Rev 1.0 | June 2026

Phase 1
Architecture

Phase 2
Pictorial

Phase 3
Schematic

Phase 4
PCB

Current phase highlighted in teal. Document grows with each phase delivered.

IoT Oxygen Concentrator Integration | Project Documentation - Phase 1
Page 2 | Generated 22 June 2026

## Table of Contents

Page 3 | Generated 22 June 2026

## 1. Project Overview

This document describes the design and implementation of an IoT integration system for an existing PSA (Pressure Swing Adsorption) oxygen concentrator. The concentrator itself is a commercially acquired, working medical device. No modifications are made to its internal components. Instead, an external integration module is built and housed in a separate enclosure, connected to the concentrator via tubes (for oxygen sampling) and wires (for power and compressor control).

What the integration system does:
Measures oxygen purity: Two OCS-3FL2.0 ultrasonic sensors are placed before and after the filtration stage. This gives a real-time comparison of raw and purified oxygen concentration.

Provides visual feedback: A 0.96-inch OLED display shows live readings from both sensors, system status, GSM signal strength, and system uptime.

Alerts the caregiver: If purity drops below the first threshold (85%), the system sounds a buzzer and sends an SMS to a registered caregiver number. If purity falls further below the second threshold (70%), the buzzer pattern becomes more persistent and the system places a voice call to the caregiver instead.

Controls the compressor: A relay circuit, driven by an optocoupler and transistor, can cut power to the concentrator compressor when oxygen purity is critically low. This protects the patient from receiving dangerously low-purity output.

Operates independently: There is no smartphone app. The system is self-contained. Caregiver contact details are configurable via USB serial (initial setup) or via incoming SMS command (field update).

NOTE: This integration does not modify the internal circuits of the oxygen concentrator. All electrical connections to the concentrator are limited to: (1) the AC mains feed to the compressor relay, and (2) the oxygen outlet tube for sensor sampling.

Page 4 | Generated 22 June 2026

## 2. System Architecture

The integration system is built around the ESP32-S3 DevKitC-1 microcontroller, which serves as the central processing unit. All sensors, communication modules, output devices, and control circuitry connect to it. The diagram below describes the high-level data and power flow across the system.

Block-level signal flow:

AC Mains Input
(from concentrator internal supply)

12V AC-DC Module
Rectified 12V DC output

LM2596 Step-Down
Regulated 5V output

From 5V: ESP32-S3, SIM800L (via 1N4001 voltage drop), OLED, Buzzer, Relay driver circuit.

From 12V: Both OCS-3FL2.0 purity sensors (Pin 1 power input).

Data paths:

Signal Path | Interface | Direction | Notes
Sensor 1 (pre-filter) to ESP32-S3 | UART1 @ 9600 baud | Sensor to MCU | 3.3V TTL, direct connection
Sensor 2 (post-filter) to ESP32-S3 | UART2 @ 9600 baud | Sensor to MCU | 3.3V TTL, direct connection
SIM800L to ESP32-S3 | UART0 @ 9600 baud | Bidirectional | AT command interface
OLED to ESP32-S3 | I2C (SDA/SCL) | MCU to display | 3.3V, address 0x3C
Relay driver to compressor | GPIO + optocoupler | MCU to load | Isolated drive via PC817
Buzzer | GPIO (PWM capable) | MCU to output | Active or passive buzzer

Page 5 | Generated 22 June 2026

## 3. Power Architecture

The integration system draws all its power from the oxygen concentrator's existing AC supply. A dedicated 12V AC-to-DC module converts mains AC to a stable 12V DC rail. This 12V rail feeds the two purity sensors directly and also supplies an LM2596 buck converter, which steps the voltage down to a regulated 5V for the rest of the system.

### 3.1 The 12V Rail

The 12V rail supplies only the two OCS-3FL2.0 sensors. These sensors accept 5V to 12V on their power pin, but 12V gives a clean, well-regulated supply that is available directly from the AC-DC module without an extra conversion stage.

### 3.2 The LM2596 Buck Converter (5V Rail)

The LM2596 is a switching step-down (buck) regulator. It takes the 12V input and produces a stable 5V output capable of supplying up to 3A continuous current. This 5V rail powers the ESP32-S3 DevKit (via its 5V/VIN pin), the SIM800L GSM module (through a voltage drop circuit described below), the OLED display (through the ESP32-S3 onboard 3.3V LDO), the buzzer, and the relay coil drive circuit.

### 3.3 SIM800L Supply (Voltage Drop Circuit)

The SIM800L operates at 3.4V to 4.4V. It must NOT be connected directly to the 5V rail, as this exceeds its maximum supply voltage. To bring 5V down to the required range, a 1N4001 rectifier diode is placed in series with the SIM800L VCC pin. A silicon diode drops approximately 0.6V to 0.7V in forward bias, so the voltage presented to SIM800L becomes approximately 4.3V to 4.4V, which is within its safe operating window.

A 1000 uF electrolytic capacitor is placed across the SIM800L VCC and GND pins. This is critical. The SIM800L draws burst currents of up to 2A when transmitting GSM signals. Without a bulk capacitor, these current spikes cause the supply voltage to collapse momentarily, crashing the module or causing reset loops. The 1000 uF capacitor acts as a local charge reservoir, absorbing these transient demands.

NOTE: Always install the 1000 uF capacitor as physically close to the SIM800L VCC and GND pins as possible. Long traces between the capacitor and the module reduce its effectiveness during current spikes.

Rail | Voltage | Source | Consumers
12V DC | 12V | AC-DC module | OCS-3FL2.0 Sensor 1, Sensor 2
5V DC | 5V | LM2596 from 12V | ESP32-S3, Relay circuit, Buzzer, SIM800L drop circuit
SIM800L supply | ~4.3V | 5V via 1N4001 diode | SIM800L VCC only
3.3V DC | 3.3V | ESP32-S3 onboard LDO | OLED, Sensor UART (logic level)

Page 6 | Generated 22 June 2026

## 4. Component Descriptions

This section describes every component in the integration module, its role in the system, and relevant operating parameters. Cross-reference with the Bill of Materials (BOM) provided separately.

### 4.1 ESP32-S3 DevKitC-1

The ESP32-S3 is the central microcontroller of the integration system. It was chosen over the standard ESP32 because this project requires three independent hardware UART channels simultaneously (two for the oxygen sensors and one for the SIM800L), while still keeping UART0 free for USB debug output. The standard ESP32 has only three UARTs total, leaving no comfortable margin. The S3 variant provides the same peripheral set with more GPIO flexibility.

The ESP32-S3 DevKitC-1 board includes a USB-to-serial bridge for programming, a 3.3V LDO regulator, and all GPIO broken out to 0.1-inch headers. It runs at 240 MHz, has 512 KB of SRAM, and supports Wi-Fi and Bluetooth (neither of which are used in this project). Programming is done via the Arduino framework or ESP-IDF using a USB cable.

### 4.2 LM2596 Buck Converter Module

The LM2596 is a switching voltage regulator configured as a step-down (buck) converter. The pre-built module used in this project includes the LM2596 IC, an inductor, output capacitor, and a potentiometer for adjusting the output voltage. Before installation, the output must be adjusted to exactly 5.0V using a multimeter with no load connected. The LM2596 can supply up to 3A, which is sufficient for all 5V loads in this system combined.

4.3 12V AC-to-DC Power Module
This module converts the mains AC voltage from the oxygen concentrator into a regulated 12V DC supply. It is tapped from the concentrator's internal AC wiring before the compressor switch, so the integration system receives power whenever the concentrator is plugged in, regardless of relay state.

4.4 0.96-inch OLED Display (I2C)
A 128x64 pixel monochrome OLED display connected via I2C. It operates at 3.3V and communicates using SDA and SCL lines. The I2C address is typically 0x3C (verify with an I2C scanner if the display does not initialise). The display shows sensor 1 oxygen percentage, sensor 2 oxygen percentage, current alert status, GSM signal strength (RSSI), and system uptime in seconds or minutes.

### 4.5 Active Buzzer

An active buzzer contains an internal oscillator and produces a tone when DC voltage is applied. It is driven from a GPIO pin through a current-limiting arrangement. The buzzer pattern varies by alert level: a short, intermittent beep for the first threshold (85%), and a persistent, rapid pattern for the second threshold (70%). The firmware uses PWM or GPIO toggling to generate these patterns.

Page 7 | Generated 22 June 2026

4.6 1N4001 Rectifier Diode
A general-purpose silicon rectifier diode used in series with the SIM800L power supply line. In forward bias, it drops approximately 0.6V to 0.7V, reducing the 5V rail to approximately 4.3V to 4.4V, which is within the SIM800L safe operating range. The 1N4001 is rated for 1A continuous current, which is sufficient for average SIM800L consumption, though the 1000 uF capacitor handles the transient burst demand.

4.7 1000 uF Electrolytic Capacitor
Placed directly across SIM800L VCC and GND. Provides bulk capacitance to absorb the high current spikes (up to 2A peak) that the SIM800L draws during GSM transmission bursts. Without this capacitor, the supply rail collapses during transmission, causing the module to reset. Polarity must be observed: the positive lead connects to VCC, the negative lead to GND.

Page 8 | Generated 22 June 2026

## 5. OCS-3FL2.0 Oxygen Purity Sensor

The OCS-3FL2.0 (WinPower Ultrasonic Oxygen Sensor, 2026 model) is an industrial-grade sensor designed specifically for PSA oxygen concentrators. It measures oxygen concentration, gas flow rate, and gas temperature simultaneously, transmitting all three values over a single UART interface every 500 ms. Two of these sensors are used in this project: one installed before the filtration stage and one after.

### 5.1 Key Specifications

Parameter | Value
Concentration range | 21% to 95.6% O2
Concentration resolution | 0.1%
Concentration accuracy | +/- 1.5% FS at 5 to 55 degrees C
Flow range | 0 to 20 L/min
Flow resolution | 0.1 L/min
Flow accuracy | +/- 0.2 L/min or 5% reading (whichever is larger)
UART output interval | Every 500 ms (automatic reporting mode)
UART baud rate | 9600 bps
UART logic level | 3.3V TTL (direct connection to ESP32-S3, no level shifting needed)
Warm-up time | 10 seconds to specified accuracy
Power supply | DC 5V to 12V, 50 mA
Working temperature | 5 to 55 degrees C
Working humidity | 5% to 85% RH (no condensation)
Gas sample requirement | No condensation, dust filtration less than 1 um
Connector | J2 socket, 4-pin

### 5.2 Connector Pinout (J2 Socket)

Pin | Function | Notes
Pin 1 | VCC (Power input) | Connect to 12V or 5V DC. 12V used in this project.

Page 9 | Generated 22 June 2026
Pin 2 | RXD | Data input to sensor (from ESP32-S3 TX pin)
Pin 3 | TXD | Data output from sensor (to ESP32-S3 RX pin)
Pin 4 | GND | Common ground

NOTE: Sensor TXD connects to the ESP32-S3 RX pin, and sensor RXD connects to the ESP32-S3 TX pin. This cross-connection is correct and intentional. A common wiring mistake is connecting TX to TX and RX to RX, which results in no data.

### 5.3 Placement in the System

Sensor 1 is placed on the raw oxygen outlet of the concentrator, before the primary filtration or molecular sieve output. Sensor 2 is placed on the final oxygen outlet tube, after all filtration stages. By comparing the two readings, the system can identify whether a drop in purity is occurring at the filtration stage or further downstream. Both sensors must be installed in-line with the oxygen tube, following the arrow marked on the sensor body that indicates gas flow direction.

Page 10 | Generated 22 June 2026

## 6. UART Communication and Sensor Protocol

UART (Universal Asynchronous Receiver/Transmitter) is a serial communication protocol that transmits data one bit at a time over two wires: TX (transmit) and RX (receive). Both devices must agree on the same baud rate (number of bits per second) for communication to work correctly. The OCS-3FL2.0 sensor uses 9600 bps, 8 data bits, 1 stop bit, and no parity check.

### 6.1 Sensor Operating Modes

The sensor operates in two modes. In automatic reporting mode, it transmits a data packet every 500 ms without any command from the microcontroller. This mode activates automatically if the sensor does not receive a query command within 4 seconds. In query/response mode, the microcontroller sends a 4-byte query command and the sensor responds immediately with a data packet. This project uses automatic reporting mode for simplicity, meaning the ESP32-S3 simply listens on each UART channel and parses incoming packets.

### 6.2 Data Packet Structure

Every data packet transmitted by the sensor is 9 bytes long, all in hexadecimal. The packet structure is fixed and must be validated before the data is used. Validation requires checking that the first three bytes match the expected header values, and that the checksum (last byte) equals the sum of all preceding bytes, truncated to 8 bits.

Byte Index | Hex Value | Field | Description
Byte 0 | 0x16 | Header 1 | Fixed identifier, must equal 0x16
Byte 1 | 0x09 | Header 2 | Fixed identifier, must equal 0x09
Byte 2 | 0x01 | Header 3 | Fixed identifier, must equal 0x01
Bytes 3-4 | -- | O2 Concentration | 16-bit value: (Byte3 x 256 + Byte4) / 10 = % O2
Bytes 5-6 | -- | Flow Rate | 16-bit value: (Byte5 x 256 + Byte6) / 10 = L/min
Bytes 7-8 | -- | Temperature | 16-bit value: (Byte7 x 256 + Byte8) / 10 = degrees C
Byte 8 (last) | -- | Checksum (CS) | Sum of bytes 0 through 7, modulo 256

### 6.3 Packet Parsing Example (C/Arduino style)

uint8_t buf[9];

// Read 9 bytes from UART into buf[]

Page 11 | Generated 22 June 2026

// Step 1: Validate header

if (buf[0]==0x16 && buf[1]==0x09 && buf[2]==0x01) {

// Step 2: Validate checksum

uint8_t cs = 0;

for (int i = 0; i < 8; i++) cs += buf[i];

if (cs == buf[8]) {

// Step 3: Extract values

float o2_pct = (buf[3]*256 + buf[4]) / 10.0; // Oxygen %

float flow = (buf[5]*256 + buf[6]) / 10.0; // L/min

float temp_c = (buf[7]*256 + buf[8]) / 10.0; // degrees C

}

}

Note: The checksum in the packet description uses byte index 8 for both temperature high byte and checksum. In the actual 9-byte packet, bytes 7 and 8 are temperature high and low, and byte 8 (the 9th byte) is the checksum. Always refer to the manufacturer datasheet for exact byte count confirmation during implementation.

Page 12 | Generated 22 June 2026

## 7. Relay Driver Circuit

The relay switches the compressor power supply on or off based on the oxygen purity level. Because the relay coil is connected to mains-voltage-switching contacts, it is essential that the ESP32-S3 microcontroller is electrically isolated from the relay and load circuit. This isolation is achieved using a two-stage driver: an optocoupler (PC817) followed by an NPN transistor (BC337).

### 7.1 Circuit Topology and Signal Flow

Stage 1 - ESP32-S3 GPIO Output
The ESP32-S3 drives a GPIO pin HIGH (3.3V) to activate the relay, or LOW (0V) to deactivate it. The GPIO never connects directly to any component that touches the relay coil side.

Stage 2 - Current Limiting Resistor (220 ohm)
The GPIO output connects through a 220 ohm resistor to the anode of the PC817 input LED. The PC817 input LED has a forward voltage of approximately 1.2V. With 3.3V on the GPIO: I = (3.3 - 1.2) / 220 = 9.5 mA. This is within the PC817 recommended input current range of 5 mA to 50 mA.

Stage 3 - PC817 Optocoupler
The PC817 is an optocoupler, meaning it transmits signals using light rather than a direct electrical connection. Inside the package, an infrared LED (input side) shines on a phototransistor (output side). When the input LED conducts, the phototransistor turns on, creating a path from its collector to emitter. The input and output circuits share no electrical connection whatsoever. This is the isolation barrier that protects the ESP32-S3.

Stage 4 - BC337 NPN Transistor
The PC817 phototransistor output drives the base of the BC337 NPN transistor. The BC337 is a small-signal NPN transistor rated for collector currents up to 800 mA. When the PC817 output pulls the BC337 base high, the transistor saturates and connects the relay coil to ground, energising the relay.

Stage 5 - Pull-down Resistor (10k ohm on BC337 base)
A 10k ohm resistor is connected from the BC337 base to GND. This ensures the transistor base is held firmly at 0V when the PC817 output is off, preventing the relay from being triggered by noise or floating inputs. This is especially important during ESP32-S3 boot-up, when GPIO states are briefly undefined.

Stage 6 - Flyback Diode (1N4001 or 1N4007)
The relay coil is an inductive load. When the BC337 switches off and the coil current is interrupted, the magnetic field collapses and generates a large reverse voltage spike (potentially hundreds of volts for a brief instant). The flyback diode is placed across the relay coil terminals in reverse bias during normal operation. When the voltage spike occurs and reverses polarity, the diode becomes forward biased and clamps the spike, dissipating it harmlessly. Without this diode, the spike can destroy the BC337 transistor.

Page 13 | Generated 22 June 2026

DANGER: The relay contacts switch mains AC voltage. Never touch relay output terminals or the compressor wiring while the system is powered. Treat the relay output side as live mains voltage at all times.

### 7.2 Component Summary for Relay Driver

Component | Value/Part | Role
Resistor R1 | 220 ohm | Limits current through PC817 input LED from ESP32-S3 GPIO
Optocoupler | PC817 | Electrical isolation between ESP32-S3 and relay driver circuit
Transistor Q1 | BC337 NPN | Switches relay coil current to GND when activated
Resistor R2 | 10k ohm | Pull-down on BC337 base, prevents false triggering at boot
Diode D1 | 1N4001 or 1N4007 | Flyback protection across relay coil against inductive spikes
Relay | 5V coil (TBD spec) | Switches compressor AC load

Page 14 | Generated 22 June 2026

## 8. SIM800L GSM Module

The SIM800L is a compact GSM/GPRS module that provides cellular communication capability. In this project, it is used exclusively for SMS (short message service) and voice call initiation. It communicates with the ESP32-S3 using AT commands over UART at 9600 bps.

### 8.1 Network Compatibility

The SIM800L supports GSM 850/900/1800/1900 MHz quad-band. Nigerian GSM networks (MTN, Airtel, Glo, 9mobile) operate on the 900 MHz and 1800 MHz bands, which are both covered. Any active Nigerian SIM card with sufficient airtime credit for SMS and calls will work. The SIM card is inserted directly into the SIM800L module holder with the chip facing down.

### 8.2 Key AT Commands Used

AT Command | Function
AT | Basic connectivity check. Module responds with OK.
AT+CSQ | Query signal strength (RSSI). Returns value 0 to 31. Display on OLED.
AT+CMGF=1 | Set SMS mode to text (not PDU). Required before sending SMS.
AT+CMGS="+234XXXXXXXXXX" | Send SMS. Follow with message text and Ctrl+Z (0x1A) to send.
ATD+234XXXXXXXXXX; | Place a voice call. The semicolon specifies a voice call, not data.
ATH | Hang up / end a call.
AT+CREG? | Check network registration status. Should return +CREG: 0,1 when registered.

NOTE: The SIM800L TX and RX logic level is 2.8V. The ESP32-S3 outputs 3.3V on its TX pin. A voltage divider (1k and 2k resistors) on the line from ESP32-S3 TX to SIM800L RX is recommended to bring 3.3V down to approximately 2.2V, which is within the SIM800L input threshold. The SIM800L TX to ESP32-S3 RX connection is direct (2.8V is read correctly as HIGH by the ESP32-S3 3.3V logic input).

Page 15 | Generated 22 June 2026

## 9. Alert Logic and Threshold Behaviour

The alert system monitors the oxygen purity reading from Sensor 2 (post-filtration output). This is the value that represents what the patient is actually receiving. Sensor 1 (pre-filtration) is used for comparative monitoring and displayed on the OLED, but the thresholds and relay control decisions are based on Sensor 2.

### 9.1 Threshold Definitions

Level | Threshol d | Condition | System Response
Normal | Above 85% | Purity is within safe range | No alert. Compressor runs. OLED shows green status.
Warning (Level 1) | 70% to 85% | Purity is below safe minimum | Buzzer sounds intermittent short beeps. SMS sent to caregiver. Compressor continues.
Danger (Level 2) | Below 70% | Purity is critically low, risk to patient | Buzzer sounds rapid, persistent pattern. Voice call placed to caregiver. Relay cuts compressor.

### 9.2 State Machine Description

The firmware implements a simple three-state machine: NORMAL, WARNING, and DANGER. Transitions between states are based on the most recent valid Sensor 2 reading. To prevent false triggers from a single bad packet, a debounce count is used: the system only transitions to a higher alert state after receiving a set number of consecutive readings below the threshold (recommended: 3 consecutive readings). It transitions back to a lower state immediately when readings recover, but the buzzer and compressor are only reset after sustained recovery.

### 9.3 SMS Alert Behaviour

When the system enters WARNING state, one SMS is sent to the caregiver number. The message includes the current O2 percentage from Sensor 2 and the system uptime. The SMS is not repeated unless the system recovers to NORMAL state and then drops to WARNING again. This prevents flooding the caregiver with repeated messages.

Example SMS content: 'ALERT: Oxygen purity low. Sensor reading: 82%. System uptime: 04:32 min. Please check the concentrator.'

### 9.4 Voice Call Behaviour

When the system enters DANGER state, a voice call is placed to the caregiver number. The call is held open for a configurable duration (e.g. 30 seconds) to allow the caregiver to hear the alert tone or respond. The call is then terminated with ATH. The relay simultaneously opens, cutting power to the compressor. A retry mechanism attempts the call again if the first attempt fails (no answer or network error).

Page 16 | Generated 22 June 2026

### 9.5 Relay and Compressor Control

In NORMAL and WARNING states, the relay is energised (closed), allowing the compressor to run. In DANGER state, the relay is de-energised (open), cutting compressor power. Note that the relay is wired in normally-open configuration for this purpose: the relay must be actively held closed by the ESP32-S3 during normal operation. This is a fail-safe design choice: if the ESP32-S3 loses power or crashes, the relay opens and the compressor stops, rather than continuing to run unmonitored.

DANGER: Relay wiring must follow normally-open (NO) configuration as described above. Connecting to
the normally-closed (NC) terminal inverts the safety logic and will cause the compressor to run even when the ESP32-S3 is off.

Page 17 | Generated 22 June 2026

## 10. OLED Display

The 0.96-inch 128x64 pixel OLED display provides a local real-time status view without requiring any phone or external device. It is driven over I2C using the SSD1306 or SH1106 controller (verify your specific module). Power is drawn from the ESP32-S3's onboard 3.3V rail.

Display Area | Content Shown
Line 1 | S1: XX.X% S2: XX.X% (both sensor O2 readings)
Line 2 | Flow: XX.X L/min Temp: XX.X C
Line 3 | Status: NORMAL / WARNING / DANGER
Line 4 | GSM: XX dBm SIM: OK / FAIL
Line 5 | Uptime: XXX sec or XX:XX min

Page 18 | Generated 22 June 2026

## 11. Caregiver Number Configuration

The caregiver phone number is not hardcoded in the firmware. It is stored in the ESP32-S3 non-volatile storage (NVS flash), which retains data even after power loss. Two methods are available to set or update the number:

Method A - USB Serial (Initial Setup)
Connect the ESP32-S3 to a computer via USB. Open any serial monitor (Arduino IDE, PuTTY, or similar) at 115200 baud. The system will print a menu on startup. Type the caregiver number in international format (e.g. +2348012345678) and press Enter. The number is saved to NVS and the menu exits. This is the recommended method for initial configuration before deployment.

Method B - SMS Command (Field Update)
To change the number without physical access to the device, send an SMS from any phone to the SIM card installed in the SIM800L. The SMS must follow this exact format:

SET:+2348099887766

The ESP32-S3 parses incoming SMS messages continuously. When it detects a message starting with SET:, it extracts the number that follows, validates it, saves it to NVS, and sends a confirmation SMS back to the sender. The old number is overwritten.

NOTE: The SET: command is case-sensitive. The number must include the country code in international format starting with +. Example: +2348012345678 for a Nigerian MTN number.

Page 19 | Generated 22 June 2026

## 12. ESP32-S3 Pin Assignment

The following table shows the proposed GPIO pin assignments for the ESP32-S3 DevKitC-1. Pin assignments are subject to revision when the full schematic is completed in Phase 3. GPIO numbers shown are ESP32-S3 internal GPIO numbers, not physical pin numbers on the board header.

GPIO | Function | Direction | Connected To
GPIO 17 | UART1 TX | Output | Sensor 1 RXD (pre-filter)
GPIO 18 | UART1 RX | Input | Sensor 1 TXD (pre-filter)
GPIO 19 | UART2 TX | Output | Sensor 2 RXD (post-filter)
GPIO 20 | UART2 RX | Input | Sensor 2 TXD (post-filter)
GPIO 43 | UART0 TX | Output | SIM800L RX (via voltage divider)
GPIO 44 | UART0 RX | Input | SIM800L TX
GPIO 8 | I2C SDA | Bidirection al | OLED SDA
GPIO 9 | I2C SCL | Output | OLED SCL
GPIO 10 | Relay control | Output | PC817 input LED (via 220 ohm)
GPIO 11 | Buzzer | Output (PWM) | Active buzzer positive terminal

NOTE: GPIO 43 and 44 are the default UART0 (USB debug) pins on the ESP32-S3 DevKitC-1. If UART0 is reassigned to SIM800L, debug output must move to a different UART or be disabled. Confirm pin mapping against your specific DevKitC-1 board pinout diagram before wiring.

Page 20 | Generated 22 June 2026

## 13. Enclosure and Mechanical Integration

All integration electronics are housed in a white project enclosure box placed externally beside the oxygen concentrator. The concentrator itself remains physically unmodified. The following connections pass between the enclosure and the concentrator:

Connection | Type | Description
AC power input | Electrical wire | Tapped from concentrator AC supply to 12V AC-DC module
Compressor relay output | Electrical wire | Relay contact in series with compressor AC supply line
Oxygen sample tube (Sensor 1) | Silicone or PTFE tube | In-line with oxygen path before filtration
Oxygen sample tube (Sensor 2) | Silicone or PTFE tube | In-line with oxygen path after filtration

Panel cutouts on the enclosure are needed for: the OLED display window, the buzzer grille, a SIM card access slot or door, the USB programming port, and cable glands for the oxygen tubes and power/relay wires. The GSM antenna wire for the SIM800L should be routed to exit the enclosure and be positioned away from metal surfaces for best signal reception.

Page 21 | Generated 22 June 2026

## Appendix A - Sensor UART Packet Quick Reference

The OCS-3FL2.0 sensor transmits a 9-byte packet every 500 ms in automatic mode. All values are in hexadecimal. Validate the header (bytes 0-2) and checksum (byte 8) before using the data.

Byte | 0 | 1 | 2 | 3 | 4 | 5 | 6 | 7 | 8
Fi eld | He ad er | He ad er | He ad er | O2 Hi gh | O2 Lo w | Fl ow Hi gh | Fl ow Lo w | Te m p | Ch ec ks u m
Fix ed val ue | 0x 16 | 0x 09 | 0x 01 | -- | -- | -- | -- | -- | S U M m od 25 6

O2 concentration (%) = (Byte3 x 256 + Byte4) / 10 Flow rate (L/min) = (Byte5 x 256 + Byte6) / 10 Temperature (deg C) = (Byte7 x 256 + Byte8) / 10

## Appendix B - Revision History

Revisio n | Date | Phase | Changes
Rev 1.0 | 22 Jun 2026 | Phas e 1 | Initial release. System architecture, power design, sensor protocol, relay driver, alert logic, pin assignment, enclosure overview.
Rev 1.1 | TBD | Phas e 2 | Pictorial wiring diagram added (Cirkit Designer).
Rev 1.2 | TBD | Phas e 3 | KiCad schematic inserted. Component-level circuit annotations.
Rev 1.3 | TBD | Phas e 4 | PCB layout image. Single-layer routing notes.

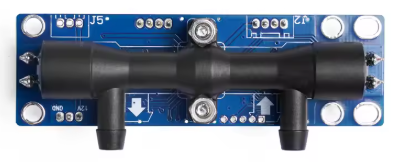
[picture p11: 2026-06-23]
docs/OCS-3FL2.0.png

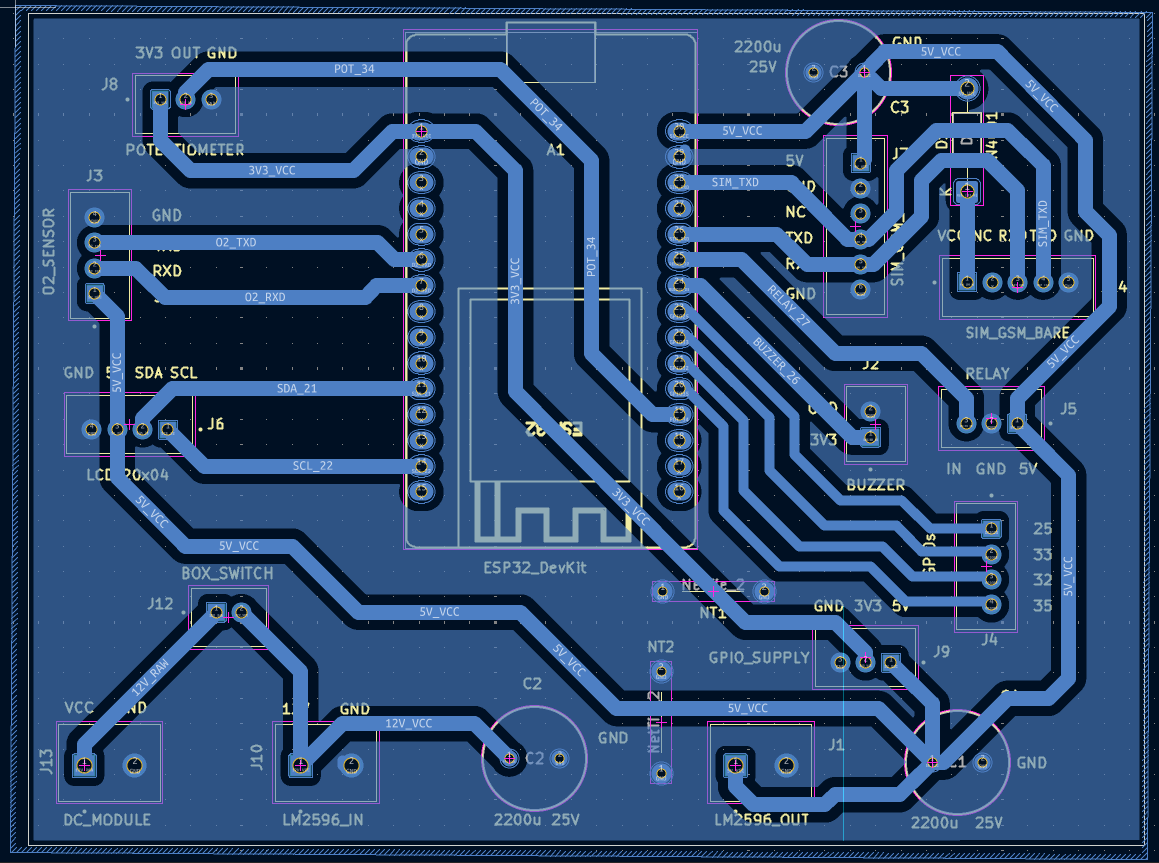
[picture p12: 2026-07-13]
docs/v2/images/2D_Image.png

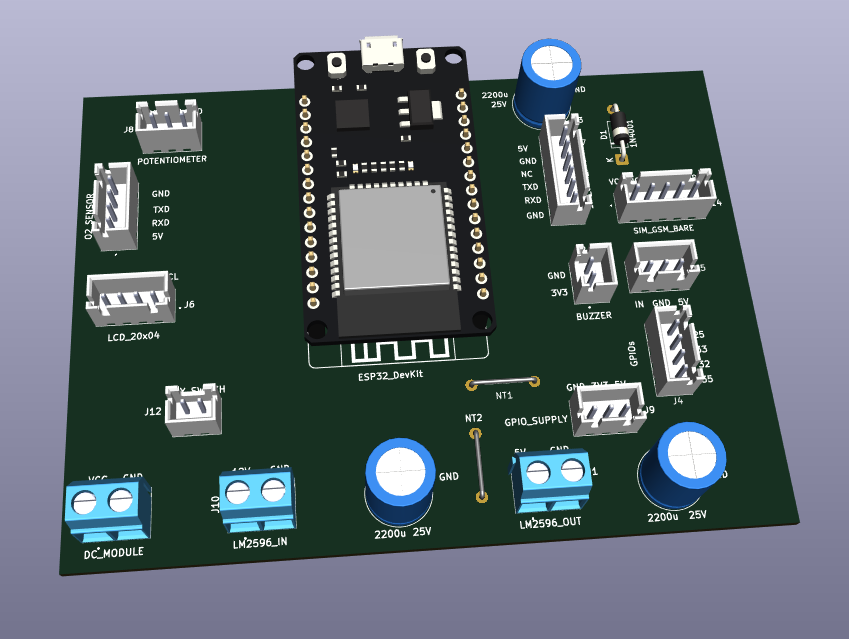
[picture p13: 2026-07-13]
docs/v2/images/3D_Angled.png

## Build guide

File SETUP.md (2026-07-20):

# Setup Guide — IoT Oxygen Concentrator Firmware

This guide walks you through setting up your computer to upload the firmware
to the ESP32. Follow every step in order. Do not skip steps.

---

## What You Need

- A computer running Windows 10/11, macOS, or Ubuntu Linux
- The ESP32 DevKit board
- A USB-A to Micro-USB cable (data cable, not charge-only)
- Internet connection for downloads

---

## Step 1 — Install Arduino IDE 2

1. Go to: https://www.arduino.cc/en/software
2. Download **Arduino IDE 2.x** for your operating system
3. Run the installer and follow the prompts
4. Launch Arduino IDE after installation

> **Windows users:** If Windows asks about installing drivers during setup, click **Install**.

---

## Step 2 — Add ESP32 Board Support

Arduino IDE does not include ESP32 support by default. You need to add it.

1. Open Arduino IDE
2. Go to **File → Preferences** (Windows/Linux) or **Arduino IDE → Preferences** (macOS)
3. Find the field labelled **"Additional boards manager URLs"**
4. Paste this URL into that field:
   ```
   https://raw.githubusercontent.com/espressif/arduino-esp32/gh-pages/package_esp32_index.json
   ```
5. Click **OK**
6. Go to **Tools → Board → Boards Manager**
7. In the search box, type: `esp32`
8. Find **"esp32 by Espressif Systems"** and click **Install**
9. Wait for the installation to complete (it downloads several files — this may take a few minutes)

---

## Step 3 — Install Required Libraries

Go to **Tools → Manage Libraries** (or press `Ctrl+Shift+I`).

Search for and install each library below. Click **Install** when found.
If asked to install dependencies, click **Install All**.

| Library Name | Author / Source | Purpose |
|---|---|---|
| `LiquidCrystal_I2C` | Frank de Brabander | LCD 2004 display via I2C |
| `TinyGSM` | Volodymyr Shymanskyy | SIM800L GSM communication |
| `ArduinoJson` | Benoit Blanchon | JSON parsing utility |
| `ESPAsyncWebServer` | **ESP32Async** (GitHub) | Captive portal HTTP server |
| `AsyncTCP` | **ESP32Async** (GitHub) | Required dependency of ESPAsyncWebServer |

> **Note:** FreeRTOS, WiFi, and DNSServer are already included in the ESP32 Arduino core.
> You do not need to install them separately.
>
> **Do not install the old `me-no-dev` forks** of AsyncTCP / ESPAsyncWebServer.
> Use only the maintained **ESP32Async** repositories (matching pair required):
>
> - https://github.com/ESP32Async/AsyncTCP (use **v3.4.x** or newer — must have `AsyncServer::status() const`)
> - https://github.com/ESP32Async/ESPAsyncWebServer (use **v3.11.x** or matching with the AsyncTCP above)
>
> **Arduino IDE:** Prefer **Sketch → Include Library → Add .ZIP Library** from the ESP32Async GitHub **Code → Download ZIP** (or a release zip).
> Library Manager sometimes installs mismatched or legacy packages under names like `ESP_Async_WebServer`.
> **PlatformIO:** `platformio.ini` already pins both via the ESP32Async GitHub URLs.
>
> **If you see:** `passing 'const AsyncServer' as 'this' argument discards qualifiers` on `_server.status()`
> that means **ESPAsyncWebServer is new but AsyncTCP is old/wrong**. Fix:
> 1. Delete **all** of these folders if present under `Documents/Arduino/libraries/`:
>    `ESP_Async_WebServer`, `ESPAsyncWebServer`, `AsyncTCP`, `Async_TCP`, `ESPAsyncTCP`
> 2. Reinstall **both** from ESP32Async only (same major generation — do not mix).
> 3. Restart Arduino IDE and compile again.

---

## Step 4 — Select the Correct Board and Port

1. Connect the ESP32 DevKit to your computer using the USB cable
2. In Arduino IDE, go to **Tools → Board → ESP32 Arduino**
3. Select **"ESP32 Dev Module"**
4. Go to **Tools → Port**
5. Select the port that appeared after you plugged in the ESP32
   - Windows: it will look like `COM3` or `COM4` (the number varies)
   - macOS/Linux: it will look like `/dev/ttyUSB0` or `/dev/cu.usbserial-...`

> **If no port appears:** The USB cable may be charge-only (no data wires). Try a different cable.
> On Windows, you may also need to install the CP2102 or CH340 USB driver manually —
> search for "CP2102 driver Windows" or "CH340 driver Windows" and download from the chip manufacturer.

---

## Step 5 — Configure Upload Settings

Go to **Tools** and confirm these settings:

| Setting | Value |
|---|---|
| Board | ESP32 Dev Module |
| Upload Speed | 921600 |
| CPU Frequency | 240MHz (WiFi/BT) |
| Flash Frequency | 80MHz |
| Flash Mode | QIO |
| Flash Size | 4MB (32Mb) |
| Partition Scheme | Default 4MB with spiffs |
| Core Debug Level | None |
| PSRAM | Disabled |

---

## Step 6 — Open and Upload the Firmware

1. Open the firmware folder and double-click `IoT_O2_Concentrator.ino`
   - It will open in Arduino IDE along with `config.h` and `portal_html.h` as tabs
2. Click the **Upload** button (the right-arrow icon, or press `Ctrl+U`)
3. Wait — you will see orange text scrolling in the output panel at the bottom
4. When you see **"Done uploading"**, the firmware is on the ESP32

> **Upload fails with "Failed to connect"?**
> Hold the **BOOT** button on the ESP32 DevKit while clicking Upload,
> then release it once the upload starts. Some boards require this.

---

## Step 7 — Set the Caregiver Phone Number

This can be done **any time**, before or after deployment, using whichever method is
most convenient. All three write to the same flash storage and take effect immediately.

**Option A — Web Portal (recommended, no cable needed)**
1. On your phone or laptop, connect to WiFi network **`O2-Controller`**, password **`12345678`**
2. A captive portal page should open automatically (if not, open a browser and visit `192.168.4.1`)
3. Scroll to the **Caregiver Number** card, type the number in international format
   (e.g. `+2348012345678`), and tap **Set**
4. You should see a confirmation and the "Current" field updates

**Option B — USB Serial**
1. After uploading, go to **Tools → Serial Monitor** (or press `Ctrl+Shift+M`)
2. Set the baud rate to **115200** (bottom-right dropdown in the Serial Monitor)
3. Type the command and press Enter:
   ```
   SET NUM +2348012345678
   ```
4. The system confirms the number is saved

**Option C — SMS (field update, no physical access needed)**
Send an SMS to the SIM card installed in the SIM800L EVB:
```
SET NUM +2348012345678
```
The device replies with a confirmation SMS and deletes the processed message.

The number is stored in flash memory (NVS) and survives power loss and reflashing
(as long as you don't erase flash entirely).

---

## Step 8 — Verify the System

With the ESP32 powered and running:

- The **LCD** should display O2 percentage, flow, temperature, status, GSM signal, and uptime across its 4 rows
- On boot, the system defaults to **Sensor mode**. With no real sensor connected, it runs a
  warm-up illusion — watch the O2 reading climb from ~21% to ~92% over about 15 seconds, then settle
- To test the full alert chain without hardware, connect to the **O2-Controller** WiFi portal,
  switch **Input Mode** to **WiFi**, and drag the O2 Purity slider down through each tier:
  - Below 85% → single beep, SMS sent
  - Below 70% → double beep, voice call placed
  - Below 35% → continuous tone, voice call placed
  - Below 23% (held for ~3 seconds) → continuous tone, voice call placed, **relay cuts off**
- Alerts are **silenced for the first 30 seconds after boot** — this is intentional, not a bug
- Check the Serial Monitor at 115200 baud for debug output if something is not working

---

## Troubleshooting

| Problem | Likely Cause | Fix |
|---|---|---|
| LCD is blank | Wrong I2C address | Run an I2C scanner sketch (search online: "Arduino I2C scanner"), note the address, update `LCD_I2C_ADDR` in `config.h` |
| LCD has blocks, no text | Contrast too low | Adjust the small potentiometer on the LCD backpack with a small screwdriver |
| Upload fails | Boot mode issue | Hold BOOT button on ESP32 during upload start |
| Upload fails | Wrong COM port | Unplug and replug USB, recheck Tools → Port |
| No COM port visible | Charge-only USB cable | Replace cable with a data cable |
| Compile error mentioning `AsyncServer` / `const` qualifiers | Mismatched AsyncTCP / ESPAsyncWebServer versions | See the library note in Step 3 — remove old copies, reinstall matching ESP32Async pair |
| Captive portal doesn't auto-open | Phone/OS didn't trigger detection | Manually open a browser and go to `192.168.4.1` |
| GSM not sending SMS or calling | SIM not registered on network | Check the LCD Row 4 GSM/SIM status; also check Serial Monitor for `[GSM]` log lines |
| Relay behaves opposite of expected | Wiring or pin assignment mismatch | Confirm `RELAY_PIN` and `BUZZER_PIN` in `config.h` match your actual wiring — these were swapped once during testing on this project, double-check before assuming firmware is at fault |
| Buzzer doesn't sound in WiFi demo mode | Not enough time held below threshold | Each tier needs ~3 consecutive readings (about 3 seconds) below its threshold before it triggers — this is intentional debounce, not a bug |
| Alerts don't fire right after boot | Boot delay active | Alerts are suppressed for the first 30 seconds after boot by design (`ALERT_BOOT_DELAY_MS` in `config.h`) |

---

## File Structure Reference

```
firmware/
├── IoT_O2_Concentrator.ino   # Main sketch — all 5 FreeRTOS tasks, alert state machine
├── config.h                   # All configurable constants (pins, thresholds, timing, WiFi AP)
└── portal_html.h              # Captive portal webpage (mode select, sliders, caregiver number)
```

All firmware logic lives in the single `.ino` file plus these two headers — there is no
separate `sensor.cpp` / `display.cpp` / `alert.cpp` split; each task is a function inside
the main sketch.

---

*Setup Guide — IoT Oxygen Concentrator Integration*
*Updated to match firmware with 5-tier alerts, 3 input modes, and web-based caregiver configuration.*
*For questions, refer to the full project documentation in the `docs/` folder.*

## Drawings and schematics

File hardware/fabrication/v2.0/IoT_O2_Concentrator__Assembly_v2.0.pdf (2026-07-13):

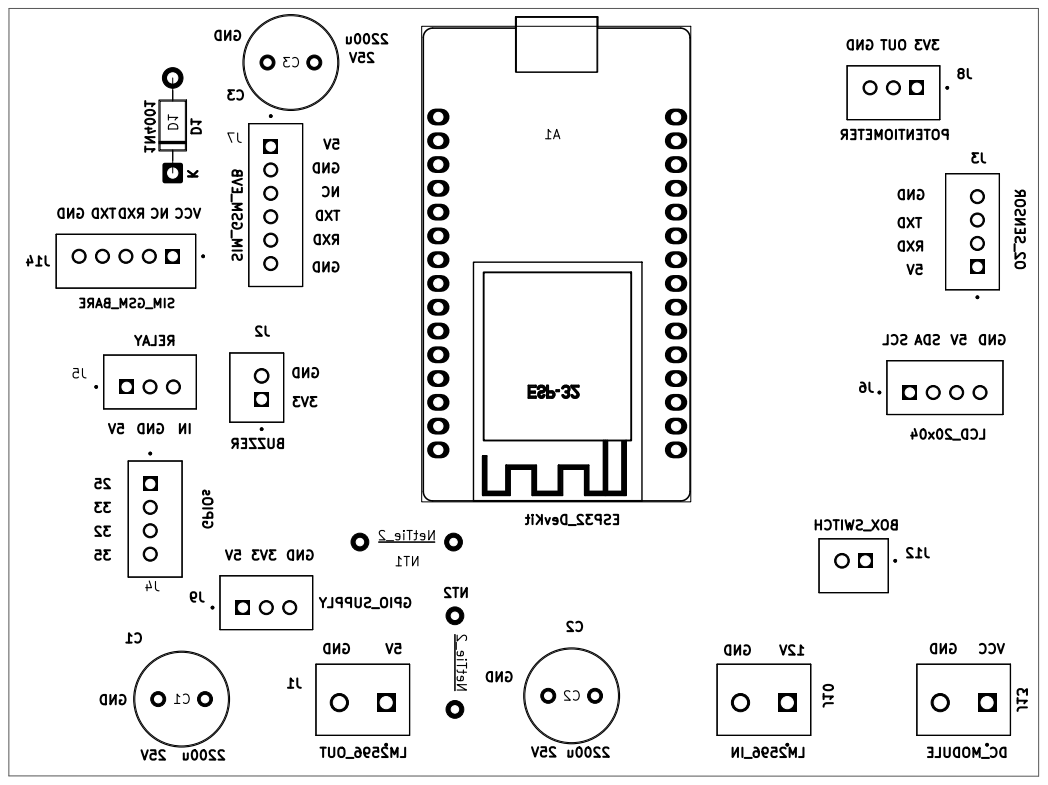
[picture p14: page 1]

SCL GND OUT GND 12V GND

GND TXD RXD NC VCC

Sheet: Black And White TOP
File: IoT_O2_Concentrator.kicad_pcb
Title: IoT_O2_Concentrator
KiCad E.D.A. 10.0.4

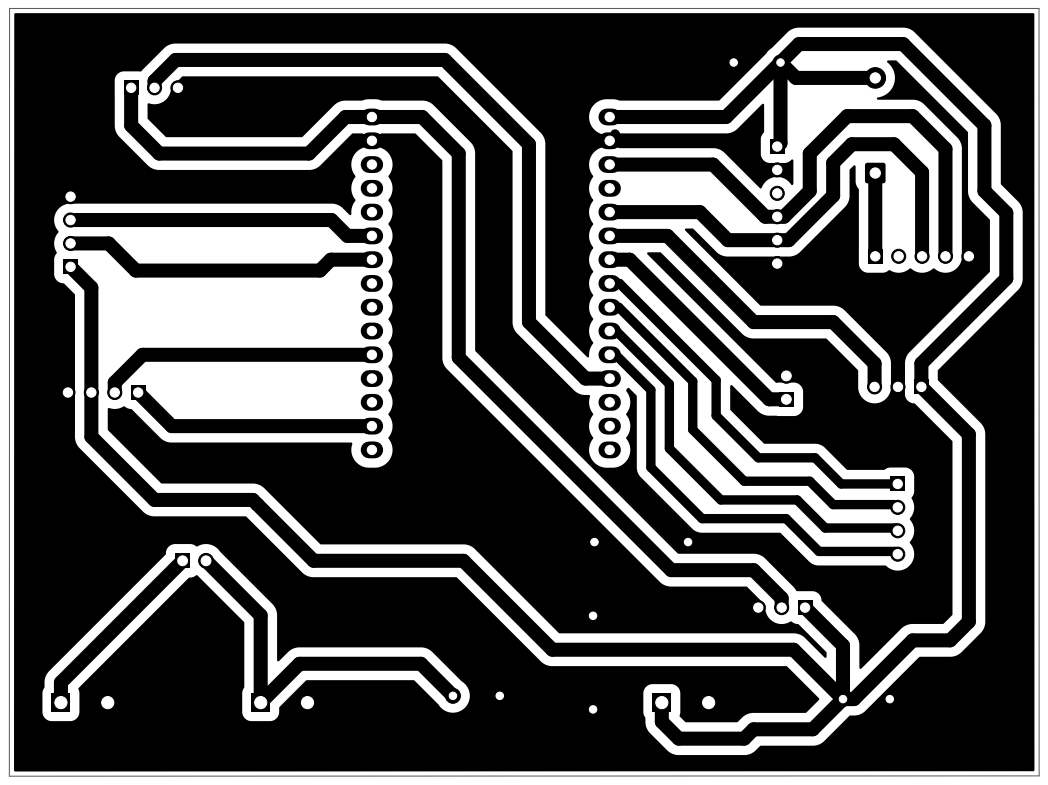
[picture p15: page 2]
D Date: 2026-07-09; Size: A4; Rev: 2.0

Board2Pdf: Black And White BOT - Page 2/2

Sheet: Black And White BOT
File: IoT_O2_Concentrator.kicad_pcb
Title: IoT_O2_Concentrator
KiCad E.D.A. 10.0.4

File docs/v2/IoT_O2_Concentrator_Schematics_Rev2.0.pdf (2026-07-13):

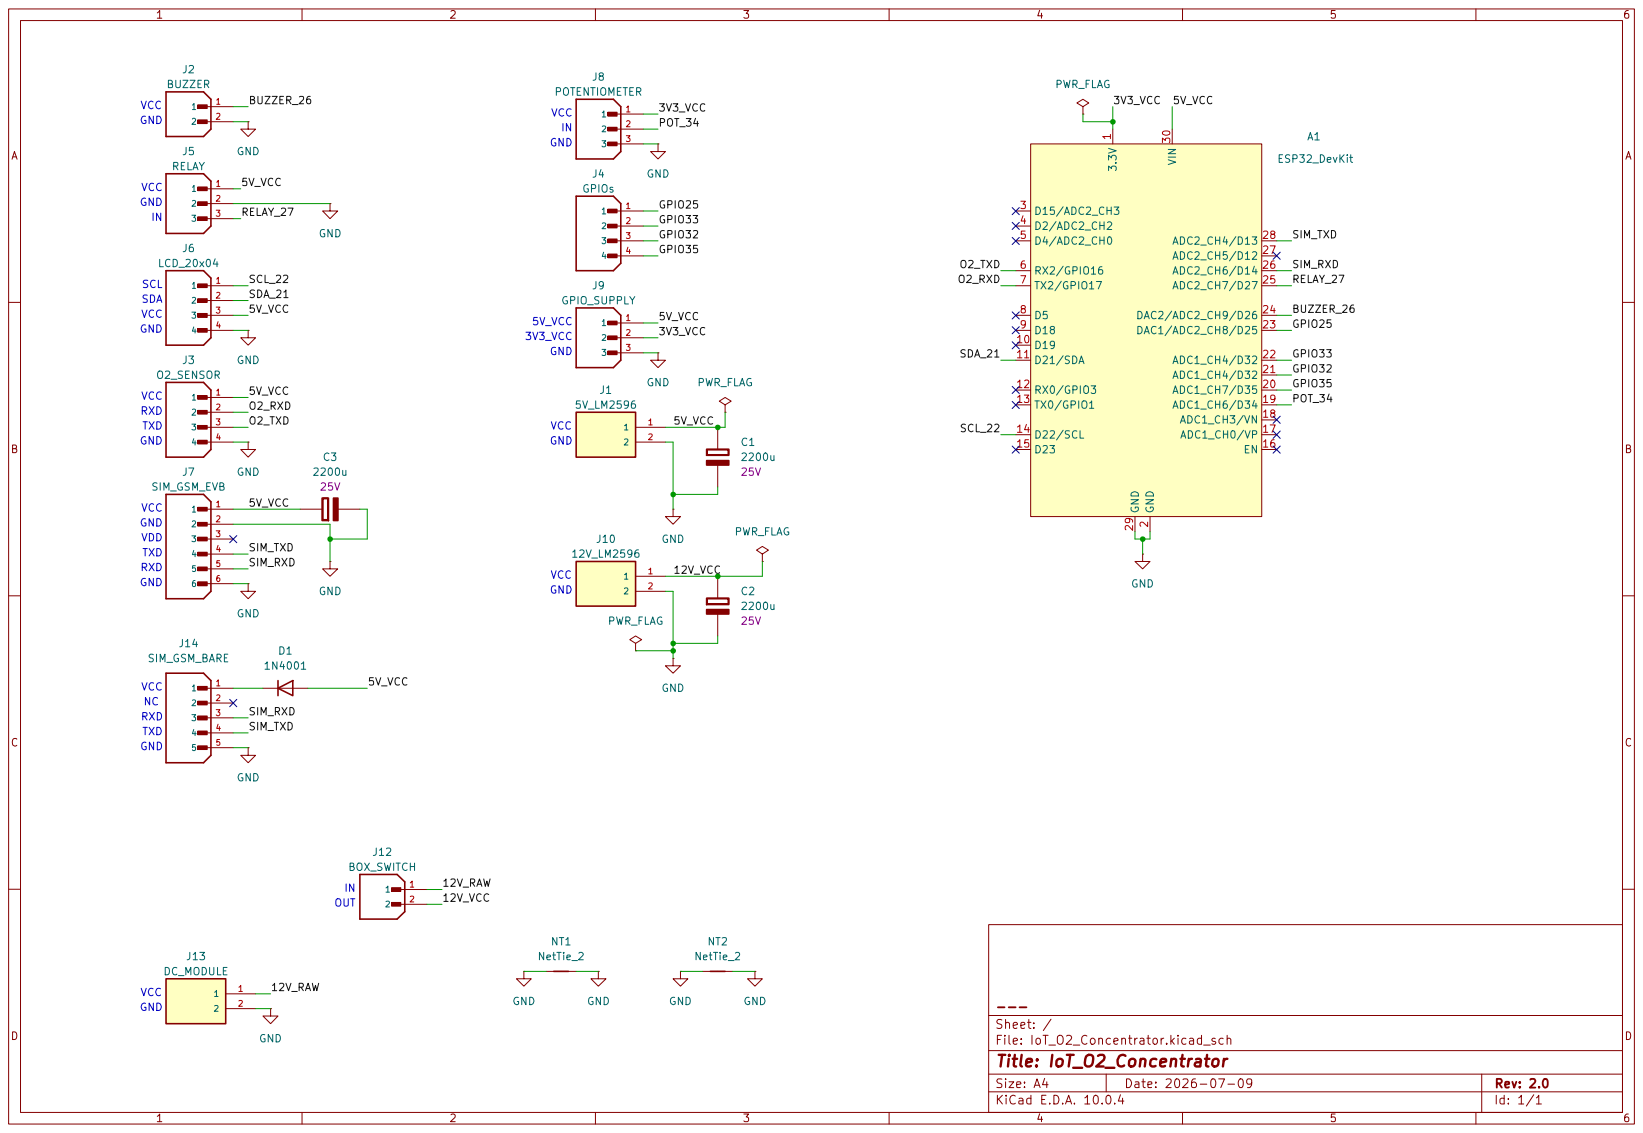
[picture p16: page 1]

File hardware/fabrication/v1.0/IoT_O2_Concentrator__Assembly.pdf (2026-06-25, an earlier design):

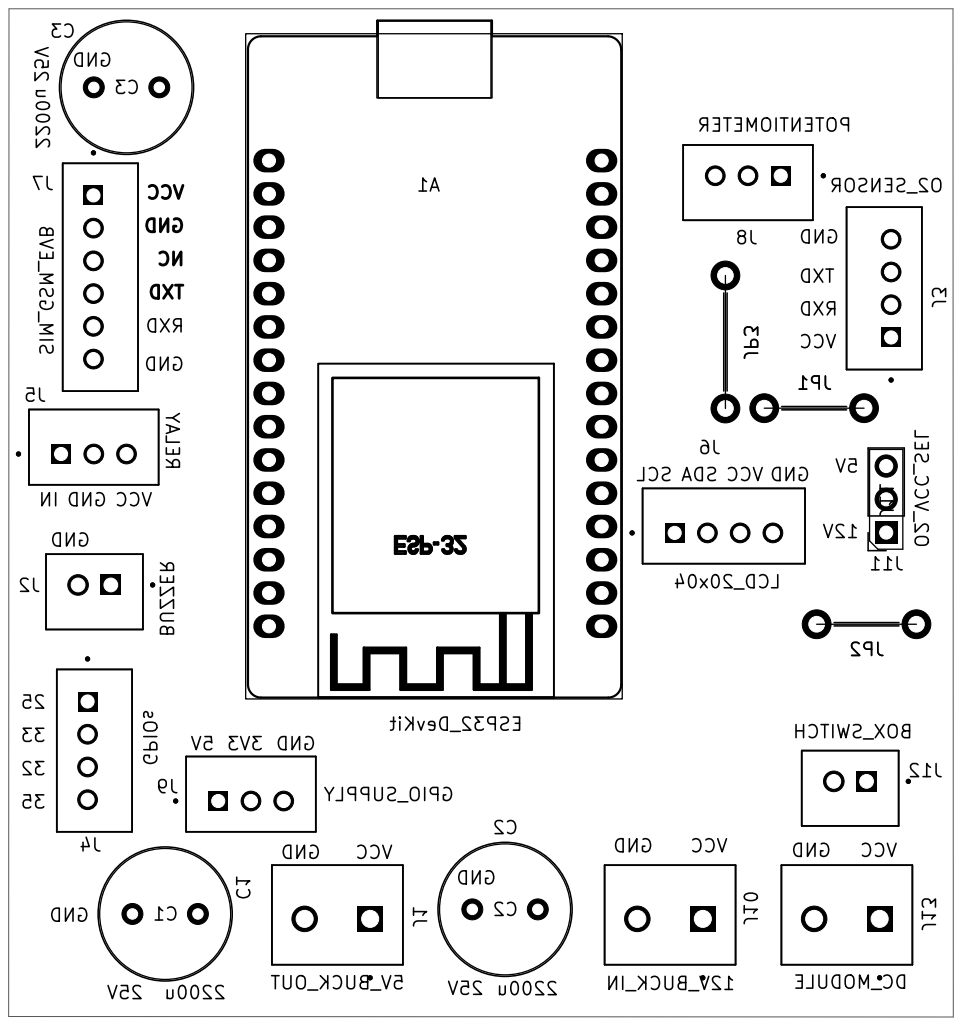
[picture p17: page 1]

Board2Pdf: Black And White TOP - Page 1/2

Sheet: Black And White TOP
File: IoT_O2_Concentrator.kicad_pcb
Title: IoT_O2_Concentrator
KiCad E.D.A. 10.0.4

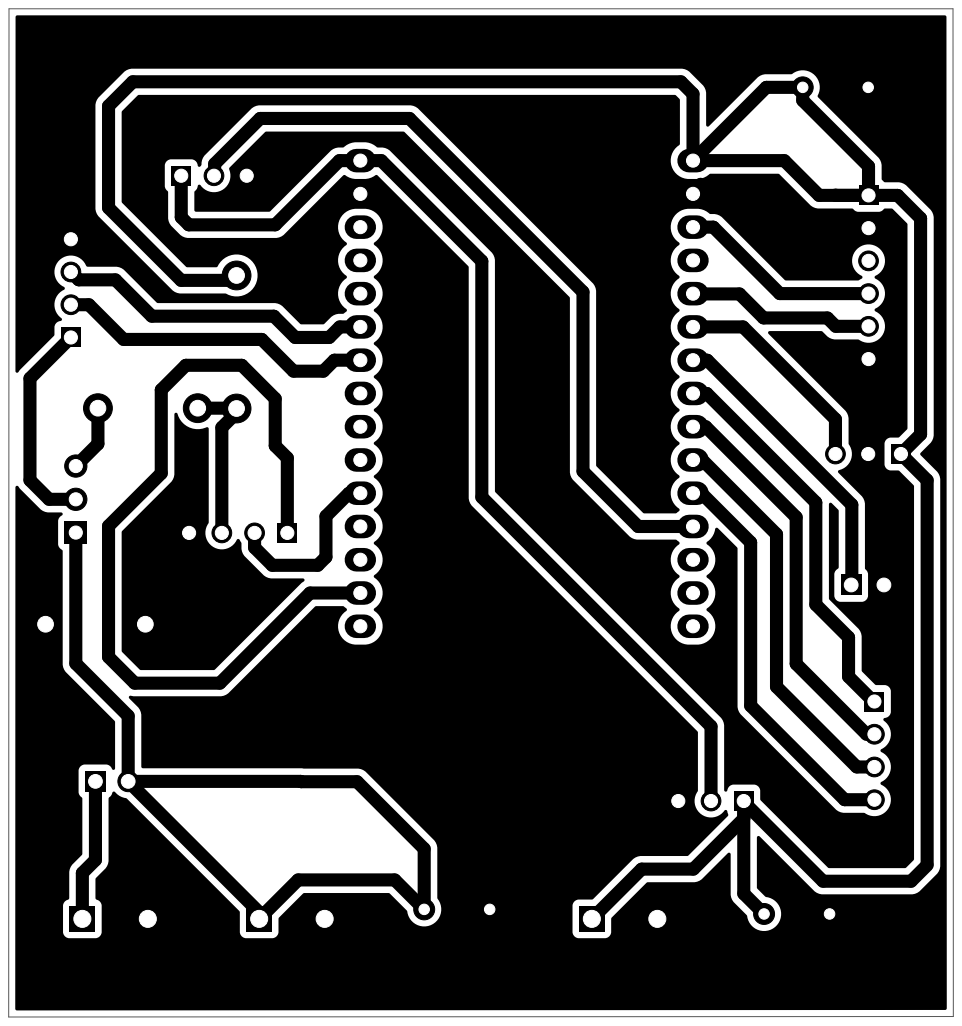
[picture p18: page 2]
D Date: 2026-06-24; Size: A4; Rev: 1.0

Board2Pdf: Black And White BOT - Page 2/2

Sheet: Black And White BOT
File: IoT_O2_Concentrator.kicad_pcb
Title: IoT_O2_Concentrator
KiCad E.D.A. 10.0.4

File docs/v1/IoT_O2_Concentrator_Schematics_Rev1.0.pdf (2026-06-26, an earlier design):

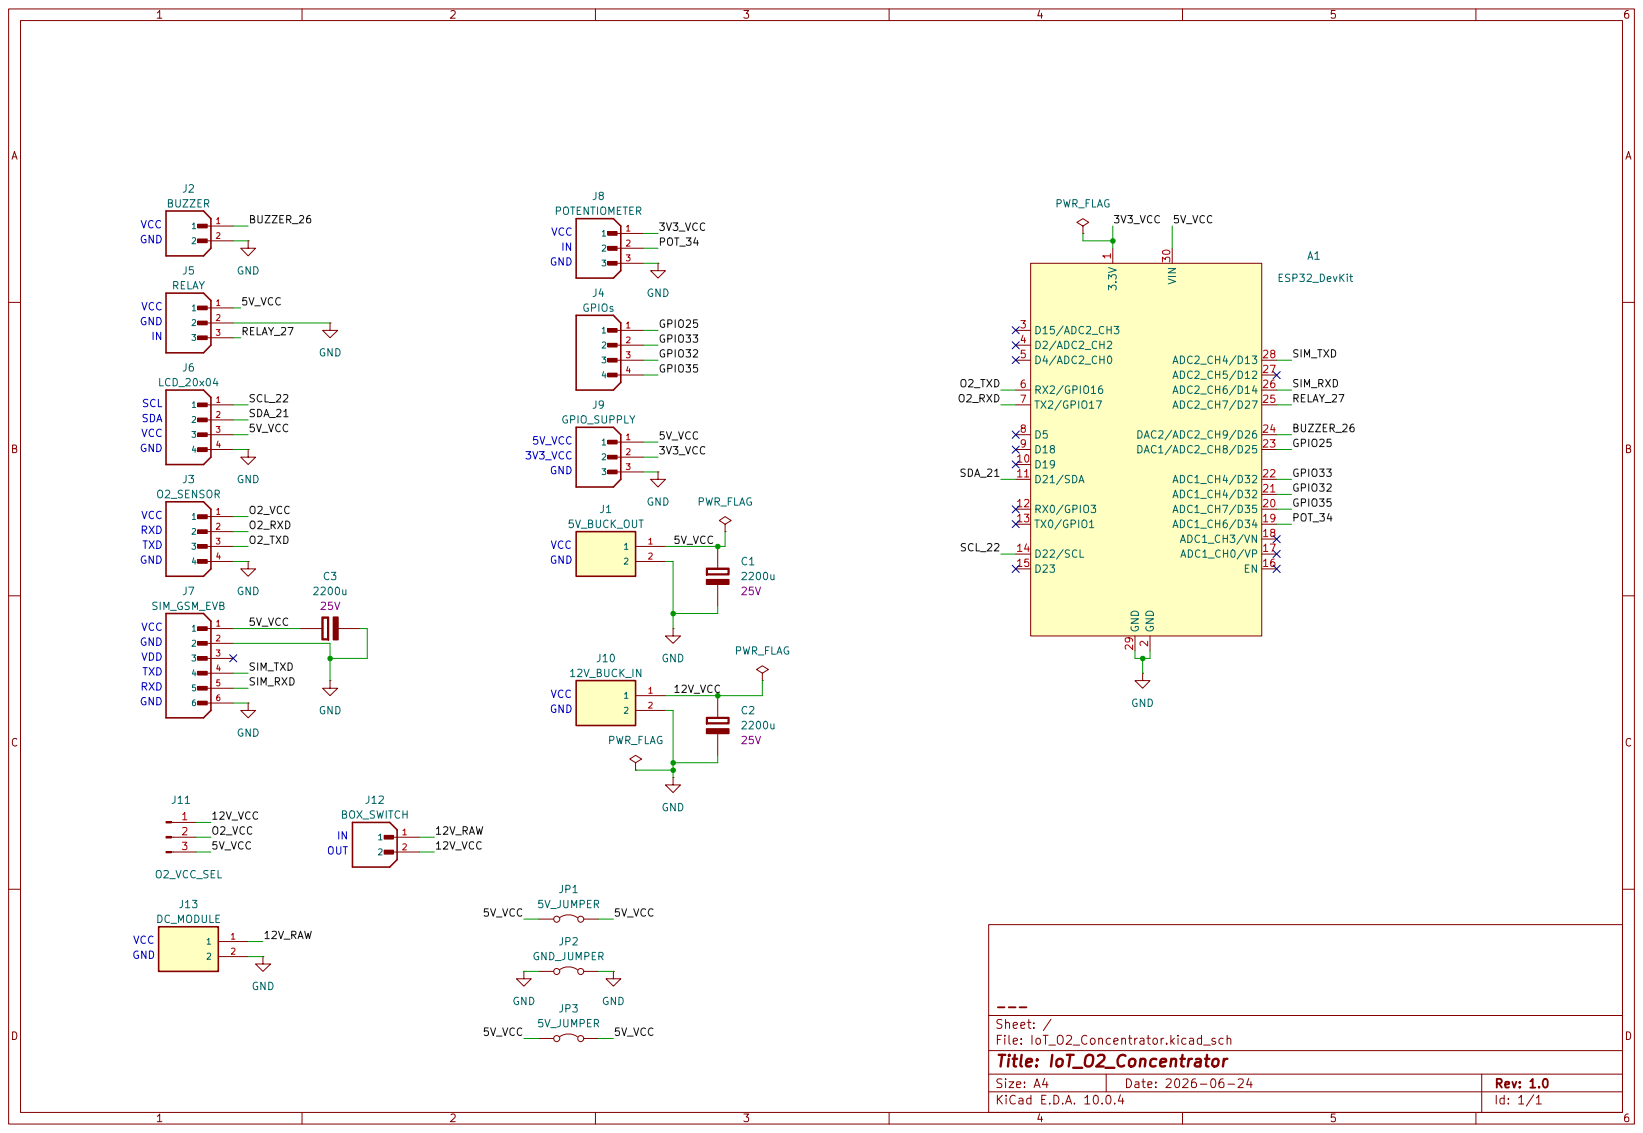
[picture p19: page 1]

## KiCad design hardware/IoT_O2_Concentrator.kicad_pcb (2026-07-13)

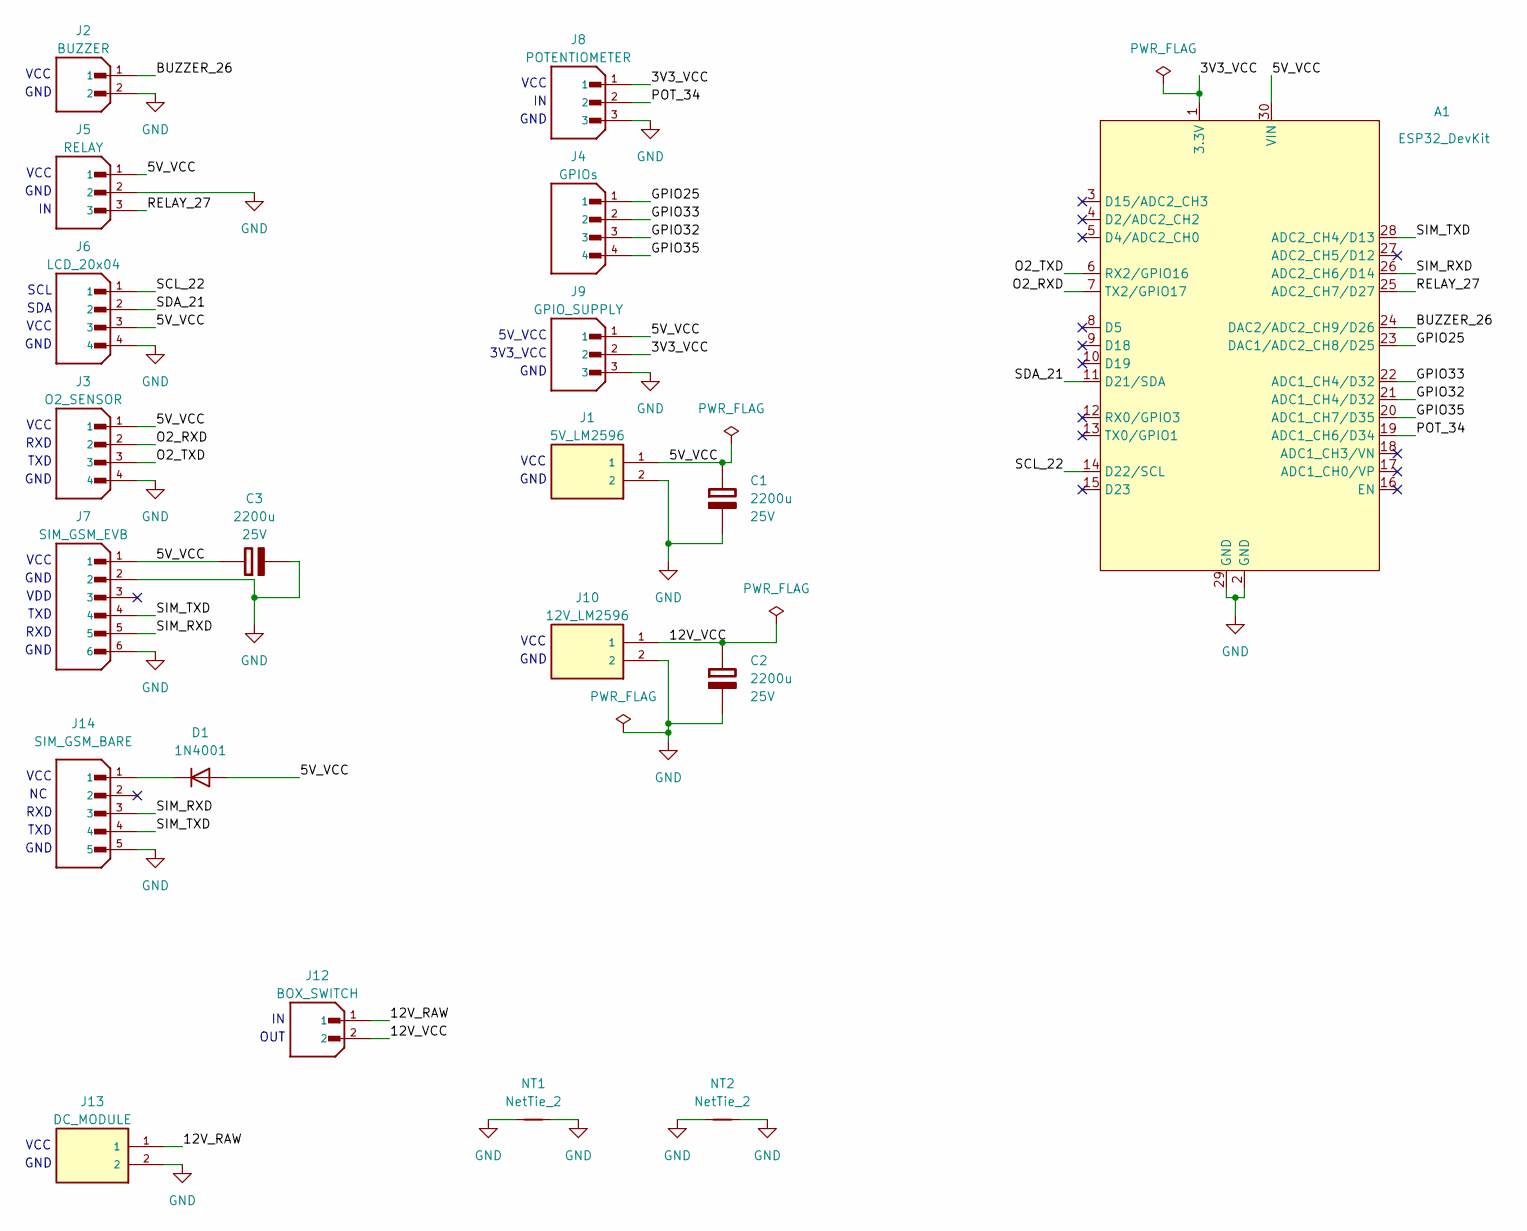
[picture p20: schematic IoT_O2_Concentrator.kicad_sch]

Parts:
A1: ESP32_DevKit; DOIT_ESP32_DEVKIT_30Pins
C1, C2, C3: 2200u; C_Radial_D10.0mm_H12.5mm_P5.00mm; Rating 25V
D1: 1N4001; D_DO-41_SOD81_P10.16mm_Horizontal
J1: 5V_LM2596; TB002-500-02BE
J2: BUZZER; JST_B2B-XH-A; PARTREV N/A
J3: O2_SENSOR; JST_B4B-XH-A; PARTREV 7/4/21
J4: GPIOs; JST_B4B-XH-A; PARTREV 7/4/21
J5: RELAY; JST_B3B-XH-A; PARTREV 7/4/21
J6: LCD_20x04; JST_B4B-XH-A; PARTREV 7/4/21
J7: SIM_GSM_EVB; JST_B6B-XH-A; PARTREV 7/4/21
J8: POTENTIOMETER; JST_B3B-XH-A; PARTREV 7/4/21
J9: GPIO_SUPPLY; JST_B3B-XH-A; PARTREV 7/4/21
J10: 12V_LM2596; TB002-500-02BE
J12: BOX_SWITCH; JST_B2B-XH-A; PARTREV N/A
J13: DC_MODULE; TB002-500-02BE
J14: SIM_GSM_BARE; JST_B5B-XH-A; PARTREV 7/4/21
NT1, NT2: NetTie_2; JUP_P10mm

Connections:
/3V3_VCC: A1.1 (3.3V), J8.1, J9.2
/5V_VCC: A1.30 (VIN), C1.1 (+), C3.1 (+), D1.2 (A), J1.1, J3.1, J5.1, J6.3, J7.1, J9.1
/12V_RAW: J12.1, J13.1
/12V_VCC: C2.1 (+), J10.1, J12.2
/BUZZER_26: A1.24 (DAC2/ADC2_CH9/D26), J2.1
/GPIO25: A1.23 (DAC1/ADC2_CH8/D25), J4.1
/GPIO32: A1.21 (ADC1_CH4/D32), J4.3
/GPIO33: A1.22 (ADC1_CH4/D32), J4.2
/GPIO35: A1.20 (ADC1_CH7/D35), J4.4
/O2_RXD: A1.7 (TX2/GPIO17), J3.2
/O2_TXD: A1.6 (RX2/GPIO16), J3.3
/POT_34: A1.19 (ADC1_CH6/D34), J8.2
/RELAY_27: A1.25 (ADC2_CH7/D27), J5.3
/SCL_22: A1.14 (D22/SCL), J6.1
/SDA_21: A1.11 (D21/SDA), J6.2
/SIM_RXD: A1.26 (ADC2_CH6/D14), J7.5, J14.3
/SIM_TXD: A1.28 (ADC2_CH4/D13), J7.4, J14.4
GND: A1.2 (GND), A1.29 (GND), C1.2 (-), C2.2 (-), C3.2 (-), J1.2, J2.2, J3.4, J5.2, J6.4, J7.2, J7.6, J8.3, J9.3, J10.2, J13.2, J14.5, NT1.1, NT1.2, NT2.1, NT2.2
unnamed: D1.1 (K), J14.1

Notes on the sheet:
GND
VCC
TXD
RXD
SCL
SDA
3V3_VCC
5V_VCC
OUT
VDD

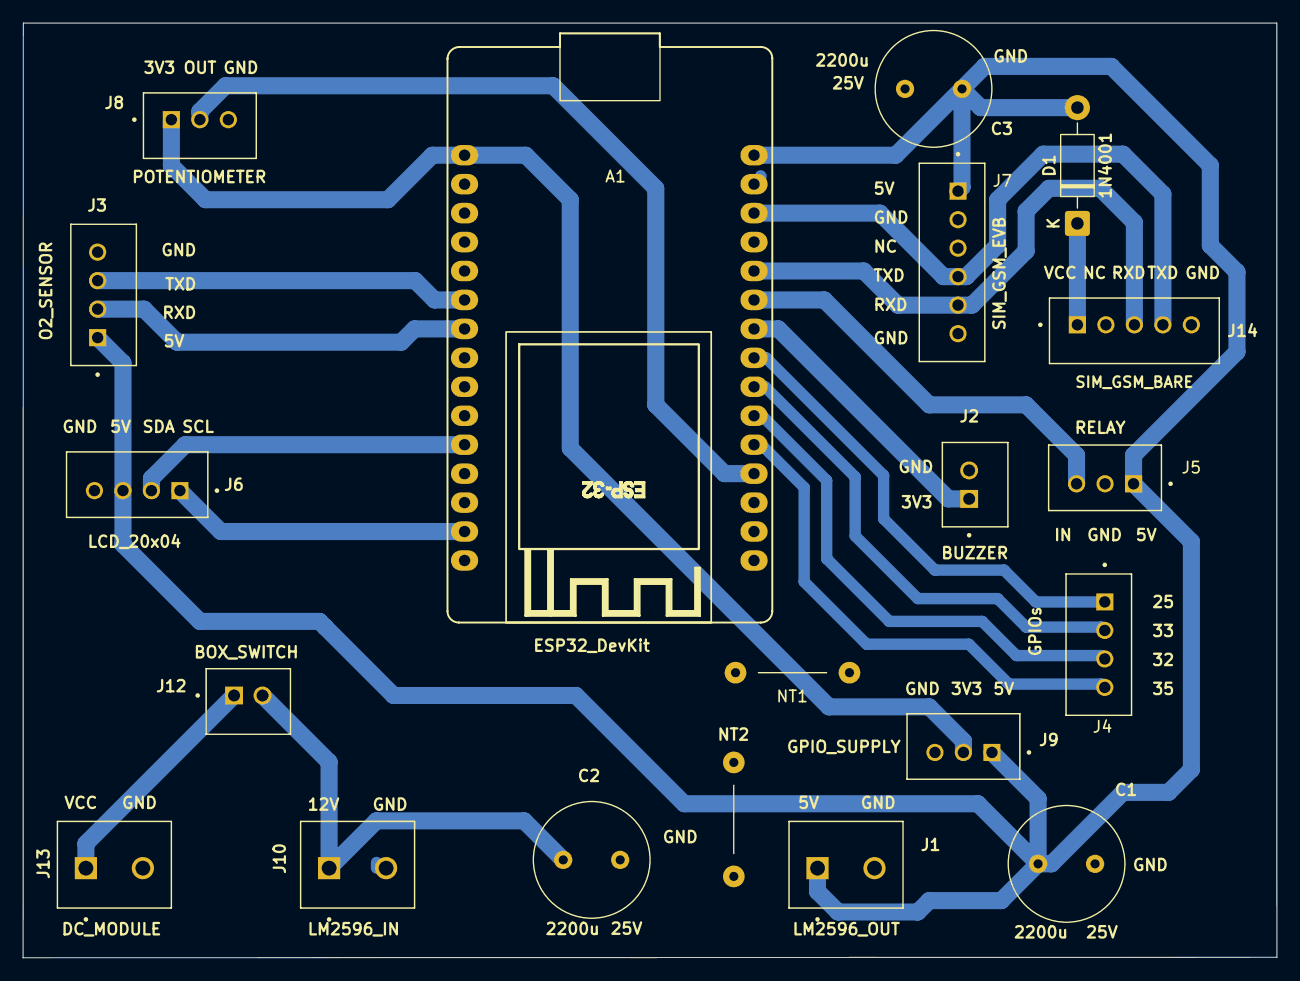
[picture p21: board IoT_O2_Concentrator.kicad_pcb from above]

Board: 2 copper layers, 110.0 x 82.0 mm, 20 parts (0 on the bottom side), 19 nets.

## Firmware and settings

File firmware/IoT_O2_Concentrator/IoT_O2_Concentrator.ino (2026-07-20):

#include <Arduino.h>
#include <Wire.h>
#include <LiquidCrystal_I2C.h>
#include <Preferences.h>
#include "config.h"   // central config file
#include "portal_html.h"
#include <TinyGsmClient.h>
#include <WiFi.h>
#include <DNSServer.h>
#include <ESPAsyncWebServer.h>

// LCD setup
LiquidCrystal_I2C lcd(LCD_I2C_ADDR, 20, 4);

// NVS
Preferences prefs;

// UARTs
HardwareSerial simSerial(1);   // SIM EVB on UART1
HardwareSerial o2Serial(2);    // Oxygen sensor on UART2

// GSM modem
TinyGsm modem(simSerial);

// === Shared Data Struct ===
struct SensorData {
  float o2;
  float flow;
  float temp;
  unsigned long uptime;
};

float O2_NORMAL_MIN     = 85.0;   // >= this = NORMAL, silent, relay ON
float O2_WARNING_MIN    = 70.0;   // 70-85 = WARNING, single beep, SMS, relay ON
float O2_DANGER_MIN     = 35.0;   // 35-70 = DANGER, double beep, call, relay ON
float O2_SEVERE_MIN     = 23.0;   // 23-35 = SEVERE, continuous tone, call, relay stays ON  (was 21.0)
                                    // < 23 (3 consecutive readings) = CRITICAL, continuous tone, call, relay OFF
String CAREGIVER_NUM    = "+2347045060874"; // default, overwritten by NVS if previously set

// GSM state machine
enum GsmState : uint8_t {
  IDLE    = 0,
  READY   = 1,
  NOSIM   = 2,
  CALLING = 3,
  CALLED  = 4,
  SMS     = 5,
  SENT    = 6,
  RETRY   = 7,
  WAIT    = 8
};

volatile GsmState gsmState = IDLE;

SensorData sharedData;

// === Input mode (always boots to sensor; not stored in NVS) ===
enum InputMode : uint8_t { MODE_POT = 0, MODE_WIFI = 1, MODE_SENSOR = 2 };
volatile InputMode inputMode = MODE_SENSOR;

// === Captive portal / WiFi demo server ===
AsyncWebServer server(80);
DNSServer dnsServer;

// === Mutexes ===
SemaphoreHandle_t dataMutex;
SemaphoreHandle_t modemMutex;

// === FreeRTOS Task Handles ===
TaskHandle_t sensorTaskHandle;
TaskHandle_t displayTaskHandle;
TaskHandle_t alertTaskHandle;
TaskHandle_t gsmTaskHandle;
TaskHandle_t configTaskHandle;
TaskHandle_t webTaskHandle;

bool sendWithRetry(std::function<bool()> action, int maxAttempts = 3, const char *tag = "RETRY");

// === Relay helpers (Active-HIGH via NPN driver, confirmed by hardware test) ===
void relayOn() {
  digitalWrite(RELAY_PIN, HIGH);   // GPIO HIGH -> NPN saturates -> relay energised -> compressor ON
}

void relayOff() {
  digitalWrite(RELAY_PIN, LOW);    // GPIO LOW -> NPN cut off -> relay de-energised -> compressor OFF
}

// === Setup ===
void setup() {

  Serial.begin(115200);
  Serial.println("[SETUP] Booting IoT O2 Concentrator...");

  prefs.begin("config", false); // namespace "config"

  // Load thresholds and caregiver number from NVS, or use defaults if not set
  O2_WARNING_MIN   = prefs.getFloat("o2_warn_min", O2_WARNING_MIN);
  O2_NORMAL_MIN    = prefs.getFloat("o2_norm_min", O2_NORMAL_MIN);
  CAREGIVER_NUM    = prefs.getString("caregiver_num", CAREGIVER_NUM);

  // Pin modes (pins now correctly assigned in config.h)
  pinMode(RELAY_PIN, OUTPUT);
  pinMode(BUZZER_PIN, OUTPUT);
  relayOff();                     // ensure compressor OFF until alert task takes over
  digitalWrite(BUZZER_PIN, LOW);  // buzzer OFF by default

  // LCD init
  Wire.begin(I2C_SDA_PIN, I2C_SCL_PIN);
  lcd.init();
  lcd.backlight();

  // UART init
  simSerial.begin(GSM_BAUD, SERIAL_8N1, SIM_RX_PIN, SIM_TX_PIN);    // SIM EVB
  o2Serial.begin(O2_BAUD, SERIAL_8N1, O2_RX_PIN, O2_TX_PIN);        // Oxygen sensor

  // Mutex init
  dataMutex  = xSemaphoreCreateMutex();
  modemMutex = xSemaphoreCreateMutex();

  // Create tasks
  xTaskCreatePinnedToCore(sensorTask,  "SensorTask",  4096, NULL, 1, &sensorTaskHandle,  0);
  xTaskCreatePinnedToCore(displayTask, "DisplayTask", 4096, NULL, 1, &displayTaskHandle, 0);
  xTaskCreatePinnedToCore(webTask,     "WebTask",     8192, NULL, 2, &webTaskHandle,     0);
  xTaskCreatePinnedToCore(gsmTask,     "GSMTask",     4096, NULL, 1, &gsmTaskHandle,     1);
  xTaskCreatePinnedToCore(configTask,  "ConfigTask",  4096, NULL, 1, &configTaskHandle,  1);
  xTaskCreatePinnedToCore(alertTask,   "AlertTask",   8192, NULL, 2, &alertTaskHandle,   1);

  Serial.println("[SETUP] All FreeRTOS tasks created.");
}

// === Sensor Task (input mode: pot / wifi / real sensor) ===
void sensorTask(void *pvParameters) {
  uint8_t buf[12];
  uint8_t idx = 0;

  // Boot-up illusion ramp state (used only in MODE_SENSOR when no real packets arrive)
  static bool  sensorRampComplete = false;
  static float sensorRampValue    = 21.0f;
  static InputMode lastMode       = MODE_SENSOR;

  for (;;) {
    switch (inputMode) {

      case MODE_POT: {
        lastMode = MODE_POT;

        // Demo: read potentiometer as O2 %
        int adcValue = analogRead(POT_PIN); // 0-4095
        SensorData sensor;
        sensor.o2     = O2_MIN_PERCENT + (adcValue / ADC_MAX_VALUE) * (O2_MAX_PERCENT - O2_MIN_PERCENT);
        sensor.flow   = 0.0;
        sensor.temp   = 25.0;
        sensor.uptime = millis() / 1000;

        if (xSemaphoreTake(dataMutex, portMAX_DELAY)) {
          sharedData = sensor;
          xSemaphoreGive(dataMutex);
        }

        vTaskDelay(pdMS_TO_TICKS(500));
        break;
      }

      case MODE_WIFI: {
        lastMode = MODE_WIFI;

        // Slider values are written by /update; only refresh uptime here
        if (xSemaphoreTake(dataMutex, portMAX_DELAY)) {
          sharedData.uptime = millis() / 1000;
          xSemaphoreGive(dataMutex);
        }
        vTaskDelay(pdMS_TO_TICKS(500));
        break;
      }

      case MODE_SENSOR: {
        // Reset the illusion ramp only when freshly entering SENSOR mode
        if (lastMode != MODE_SENSOR) {
          sensorRampComplete = false;
          sensorRampValue    = 21.0f;
        }
        lastMode = MODE_SENSOR;

        bool gotRealPacket = false;

        // --- Try real UART first - if a real sensor is ever connected, it takes over automatically ---
        while (o2Serial.available()) {
          uint8_t b = o2Serial.read();

          // Hunt for header: 0x16, 0x09, 0x01
          if (idx == 0 && b != 0x16) continue;
          if (idx == 1 && b != 0x09) { idx = 0; continue; }
          if (idx == 2 && b != 0x01) { idx = 0; continue; }

          buf[idx++] = b;

          if (idx == 12) {
            idx = 0;

            // Checksum: sum of all 12 bytes must be 0 (mod 256)
            uint8_t cs = 0;
            for (int i = 0; i < 12; i++) cs += buf[i];

            if (cs != 0) {
              Serial.println("[SENSOR] Checksum failed, packet discarded.");
              continue;
            }

            SensorData sensor;
            sensor.o2     = ((buf[3] << 8) | buf[4]) / 10.0f;
            sensor.flow   = ((buf[5] << 8) | buf[6]) / 10.0f;
            sensor.temp   = ((buf[7] << 8) | buf[8]) / 10.0f;
            sensor.uptime = millis() / 1000;

            // Sanity check - discard physically impossible readings
            if (sensor.o2 < 15.0f || sensor.o2 > 100.0f) {
              Serial.println("[SENSOR] O2 out of range, packet discarded.");
              continue;
            }

            if (xSemaphoreTake(dataMutex, portMAX_DELAY)) {
              sharedData = sensor;
              xSemaphoreGive(dataMutex);
            }

            Serial.printf("[SENSOR] O2: %.1f%%  Flow: %.1f LPM  Temp: %.1fC\n",
                          sensor.o2, sensor.flow, sensor.temp);

            gotRealPacket = true;
          }
        }

        // --- No real sensor connected - run the boot-up illusion instead ---
        if (!gotRealPacket) {
          SensorData sensor;
          sensor.uptime = millis() / 1000;

          if (!sensorRampComplete) {
            sensorRampValue += 0.237f;   // ~15 second ramp at 50ms loop interval
            if (sensorRampValue >= 92.0f) {
              sensorRampValue    = 92.0f;
              sensorRampComplete = true;
              Serial.println("[SENSOR] Warm-up complete, holding steady reading.");
            }
            sensor.o2 = sensorRampValue;
          } else {
            // Small realistic jitter once settled, so it doesn't look frozen
            sensor.o2 = 92.0f + (random(-10, 11) / 10.0f);  // 91.0 to 93.0 wobble
          }
          sensor.flow = 4.5f + (random(-5, 6) / 10.0f);   // slight flow jitter
          sensor.temp = 24.0f + (random(-5, 6) / 10.0f);  // slight temp jitter

          if (xSemaphoreTake(dataMutex, portMAX_DELAY)) {
            sharedData = sensor;
            xSemaphoreGive(dataMutex);
          }
        }

        vTaskDelay(pdMS_TO_TICKS(50));
        break;
      }

      default:
        vTaskDelay(pdMS_TO_TICKS(500));
        break;
    }
  }
}

// === Web Task (captive portal AP + DNS + AsyncWebServer) ===
void webTask(void *pvParameters) {
  Serial.println("[WEB] Starting WiFi AP...");

  WiFi.mode(WIFI_AP);
  IPAddress apIP(192, 168, 4, 1);
  WiFi.softAPConfig(apIP, apIP, IPAddress(255, 255, 255, 0));
  WiFi.softAP(WIFI_AP_SSID, WIFI_AP_PASS);

  // DNS: redirect all hostnames to the AP IP (captive portal)
  dnsServer.start(53, "*", apIP);
  Serial.printf("[WEB] AP SSID=%s IP=%s\n", WIFI_AP_SSID, WIFI_AP_IP);

  // --- Routes ---
  server.on("/", HTTP_GET, [](AsyncWebServerRequest *request) {
    request->send(200, "text/html", PORTAL_HTML);
  });

  server.on("/setMode", HTTP_GET, [](AsyncWebServerRequest *request) {
    if (request->hasParam("mode")) {
      String mode = request->getParam("mode")->value();
      mode.toLowerCase();
      if (mode == "pot") {
        inputMode = MODE_POT;
        Serial.println("[WEB] Input mode: POT");
      } else if (mode == "wifi") {
        inputMode = MODE_WIFI;
        Serial.println("[WEB] Input mode: WIFI");
      } else if (mode == "sensor") {
        inputMode = MODE_SENSOR;
        Serial.println("[WEB] Input mode: SENSOR");
      }
    }
    request->send(200, "text/plain", "OK");
  });

  server.on("/update", HTTP_GET, [](AsyncWebServerRequest *request) {
    // Only apply slider values while WiFi demo mode is active
    if (inputMode == MODE_WIFI) {
      if (xSemaphoreTake(dataMutex, portMAX_DELAY)) {
        if (request->hasParam("purity")) {
          sharedData.o2 = request->getParam("purity")->value().toFloat();
        }
        if (request->hasParam("flow")) {
          sharedData.flow = request->getParam("flow")->value().toFloat();
        }
        if (request->hasParam("temp")) {
          sharedData.temp = request->getParam("temp")->value().toFloat();
        }
        xSemaphoreGive(dataMutex);
      }
    }
    request->send(200, "text/plain", "OK");
  });

  // --- NEW: /status with caregiver number ---
  server.on("/status", HTTP_GET, [](AsyncWebServerRequest *request) {
    SensorData snap;
    InputMode mode = inputMode;
    if (xSemaphoreTake(dataMutex, portMAX_DELAY)) {
      snap = sharedData;
      xSemaphoreGive(dataMutex);
    }

    const char *modeStr = "pot";
    if (mode == MODE_WIFI) modeStr = "wifi";
    else if (mode == MODE_SENSOR) modeStr = "sensor";

    // Get caregiver number with mutex
    String caregiver;
    if (xSemaphoreTake(modemMutex, portMAX_DELAY)) {
      caregiver = CAREGIVER_NUM;
      xSemaphoreGive(modemMutex);
    }

    char json[256];
    snprintf(json, sizeof(json),
             "{\"mode\":\"%s\",\"o2\":%.1f,\"flow\":%.1f,\"temp\":%.1f,\"caregiver\":\"%s\"}",
             modeStr, snap.o2, snap.flow, snap.temp, caregiver.c_str());
    request->send(200, "application/json", json);
  });

  // --- NEW: set caregiver number via web ---
  server.on("/setNumber", HTTP_GET, [](AsyncWebServerRequest *request) {
    if (request->hasParam("num")) {
      String num = request->getParam("num")->value();
      num.trim();
      if (num.length() > 0) {
        // Update NVS and global with mutex protection
        if (xSemaphoreTake(modemMutex, portMAX_DELAY)) {
          prefs.putString("caregiver_num", num);
          CAREGIVER_NUM = num;
          xSemaphoreGive(modemMutex);
          Serial.printf("[WEB] Caregiver number set to %s\n", num.c_str());
          request->send(200, "text/plain", "OK");
        } else {
          request->send(500, "text/plain", "Mutex error");
        }
      } else {
        request->send(400, "text/plain", "Invalid number");
      }
    } else {
      request->send(400, "text/plain", "Missing num parameter");
    }
  });

  // Captive-portal detection endpoints (Android / iOS / Windows)
  auto captiveRedirect = [](AsyncWebServerRequest *request) {
    request->redirect("http://192.168.4.1");
  };
  server.on("/generate_204", HTTP_GET, captiveRedirect);
  server.on("/hotspot-detect.html", HTTP_GET, captiveRedirect);
  server.on("/connecttest.txt", HTTP_GET, captiveRedirect);
  server.on("/redirect", HTTP_GET, captiveRedirect);

  server.begin();
  Serial.println("[WEB] AsyncWebServer started on port 80");

  for (;;) {
    dnsServer.processNextRequest();
    vTaskDelay(pdMS_TO_TICKS(10));
  }
}

// === Display Task ===
void displayTask(void *pvParameters) {

  for (;;) {
    SensorData display;
    if (xSemaphoreTake(dataMutex, portMAX_DELAY)) {
      display = sharedData;
      xSemaphoreGive(dataMutex);
    }

    lcd.setCursor(0, 0);
    lcd.print("O2: ");
    lcd.print(display.o2, 1);
    lcd.print(" %  FL:");
    lcd.print(display.flow, 1);
    lcd.print(" LPM");

    lcd.setCursor(0, 1);
    lcd.print("TMP: ");
    lcd.print(display.temp, 1);
    lcd.print("C UPT:");
    lcd.print(display.uptime);
    lcd.print("s");

    lcd.setCursor(0, 2);
    if (display.o2 >= O2_NORMAL_MIN) lcd.print("STATUS: NORMAL   ");
    else if (display.o2 >= O2_WARNING_MIN) lcd.print("STATUS: WARNING  ");
    else if (display.o2 >= O2_DANGER_MIN) lcd.print("STATUS: DANGER   ");
    else if (display.o2 >= O2_SEVERE_MIN) lcd.print("STATUS: SEVERE   ");
    else lcd.print("STATUS: CRITICAL ");

    int rssi = 0, simSt = 0;
    if (xSemaphoreTake(modemMutex, pdMS_TO_TICKS(500))) {
        rssi  = modem.getSignalQuality();
        simSt = modem.getSimStatus();
        xSemaphoreGive(modemMutex);
    }

    const char* gsmStateStr[] = {
      "Idle", "Ready", "NoSIM", "Call", "Done", "SMS", "Sent", "Retry", "Wait"
    };

    lcd.setCursor(0, 3);
    char row4[21];
    snprintf(row4, sizeof(row4), "G:%2d S:%s %-7s", rssi, simSt==1?"OK":"NO", gsmStateStr[gsmState]);
    lcd.print(row4);

    vTaskDelay(pdMS_TO_TICKS(DISPLAY_INTERVAL_MS)); // 500ms
  }
}

// === GSM Task ===
void gsmTask(void *pvParameters) {
  Serial.println("[GSM] Initializing modem...");
  modem.restart();

  for (;;) {
    if (xSemaphoreTake(modemMutex, pdMS_TO_TICKS(2000))) {
      // Check SIM status
      int simSt = modem.getSimStatus();
      if (simSt != 1) {
        gsmState = NOSIM; // no sim
        Serial.println("[GSM] SIM not ready.");
      } else {
        // Try to attach to network
        if (modem.isNetworkConnected()) {
          gsmState = READY;
        } else {
          gsmState = RETRY;
          Serial.println("[GSM] Attempting network registration...");
          if (modem.waitForNetwork(3000L)) {   // shorter non-blocking wait
            gsmState = READY;
            Serial.println("[GSM] Network registered.");
          } else {
            gsmState = RETRY;
            Serial.println("[GSM] Network not found, will retry...");
          }
        }
      }
      xSemaphoreGive(modemMutex);
    }

    // Yield to other tasks
    vTaskDelay(pdMS_TO_TICKS(5000)); // check every 5s
  }
}
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
void loop() {
  vTaskDelay(portMAX_DELAY); // everything runs in tasks
}

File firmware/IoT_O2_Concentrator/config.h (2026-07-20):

#ifndef CONFIG_H
#define CONFIG_H

#define TINY_GSM_MODEM_SIM800

// === I2C Pin Assignments ===
#define I2C_SDA_PIN           21
#define I2C_SCL_PIN           22

// === UART Pin Assignments ===
#define SIM_TX_PIN            14   // UART1 TX to SIM800L EVB SIM_RXD
#define SIM_RX_PIN            13   // UART1 RX from SIM800L EVB SIM_TXD

#define O2_TX_PIN             17   // UART2 TX to OXYGEN SENSOR_RXD
#define O2_RX_PIN             16   // UART2 RX from OXYGEN SENSOR_TXD

// === GPIO Pin Assignments (corrected) ===
#define RELAY_PIN             27   // Relay control GPIO (was 26)
#define BUZZER_PIN            26   // Buzzer GPIO (was 27)
#define POT_PIN               34   // ADC input for demo potentiometer
#define LCD_I2C_ADDR          0x27 // Default I2C address (change to 0x3F if needed)

// === Thresholds (5-tier alert system) ===
// Runtime values, loaded from NVS in setup() with these as fallback defaults.
// Declared here as extern, defined as float globals in firmware.ino.
extern float O2_NORMAL_MIN;    // >= this           = NORMAL   (silent, relay ON)
extern float O2_WARNING_MIN;   // WARNING_MIN to NORMAL_MIN  = WARNING  (single beep, SMS, relay ON)
extern float O2_DANGER_MIN;    // DANGER_MIN to WARNING_MIN  = DANGER   (double beep, call, relay ON)
extern float O2_SEVERE_MIN;    // SEVERE_MIN to DANGER_MIN   = SEVERE   (continuous tone, call, relay ON)
                                // below SEVERE_MIN (3 consecutive readings) = CRITICAL (continuous tone, call, relay OFF)

// === Timing ===
#define SENSOR_INTERVAL_MS    500    // Sensor update interval
#define DISPLAY_INTERVAL_MS   500    // LCD refresh interval
#define ALERT_INTERVAL_MS     1000   // Alert task loop interval
#define BUZZER_WARNING_MS     200    // Warning beep duration
#define BUZZER_WARNING_GAP    500    // Gap between warning beeps (changed from 1000)
#define ALERT_BOOT_DELAY_MS   30000  // Suppress all alerts (buzzer/SMS/call) for this long after boot

// === GSM Settings ===
#define GSM_BAUD              9600
extern String CAREGIVER_NUM;   // Caregiver number, loaded from NVS with demo default

// === O2 Settings ===
#define O2_BAUD               9600

// === Demo Mode Mapping ===
// Potentiometer ADC range mapped to O2 percentage
#define O2_MIN_PERCENT        21.0
#define O2_MAX_PERCENT        95.6
#define ADC_MAX_VALUE         4095.0

// === WiFi Captive Portal (demo input mode) ===
#define WIFI_AP_SSID          "O2-Controller"
#define WIFI_AP_PASS          "12345678"
#define WIFI_AP_IP            "192.168.4.1"

#endif

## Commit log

2026-06-23 Start of Kicad Schematic
    [IoT_O2_Concentrator.kicad_pcb, IoT_O2_Concentrator.kicad_sch]
2026-06-23 Snapping to grid errors
    [IoT_O2_Concentrator.kicad_sch]
2026-06-24 Started PCB routing
    [IoT_O2_Concentrator.kicad_pcb, IoT_O2_Concentrator.kicad_sch]
2026-06-24 Finishing the routing
    [IoT_O2_Concentrator.kicad_pcb, IoT_O2_Concentrator.kicad_sch]
2026-06-24 Routing with correct SIM tx/rx & labelling
    [IoT_O2_Concentrator.kicad_pcb, IoT_O2_Concentrator.kicad_sch]
2026-06-25 PCB Routing completed
    [IoT_O2_Concentrator.kicad_pcb, IoT_O2_Concentrator.kicad_sch]
2026-06-26 Corrected the firmware and added the O2 data derivation
    [IoT_O2_Concentrator.kicad_sch]
2026-06-26 Added SMS polling and NVS
    [IoT_O2_Concentrator.kicad_pcb]
2026-07-09 Hardware v2.0: bare SIM800 module support and routing cleanup
    Add JST for bare SIM module with 1N4001 drop from 5 V; remove O2 sensor voltage selector (sensor accepts 5 V). Replace routing jumpers with net ties (GND only) for DRC continuity; sheet version set to 2.0.
    [IoT_O2_Concentrator.kicad_pcb, IoT_O2_Concentrator.kicad_sch]
2026-07-13 Board V2 and firmware V2 implemented with softAP
    [IoT_O2_Concentrator.kicad_pcb, IoT_O2_Concentrator.kicad_sch]
